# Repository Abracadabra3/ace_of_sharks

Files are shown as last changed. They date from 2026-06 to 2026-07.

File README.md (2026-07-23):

# Ace of Sharks Combat Robot

**Ace of Sharks is a plastic antweight (1 lb) combat robot with a compound grab and lift motion powered by a single servo.**

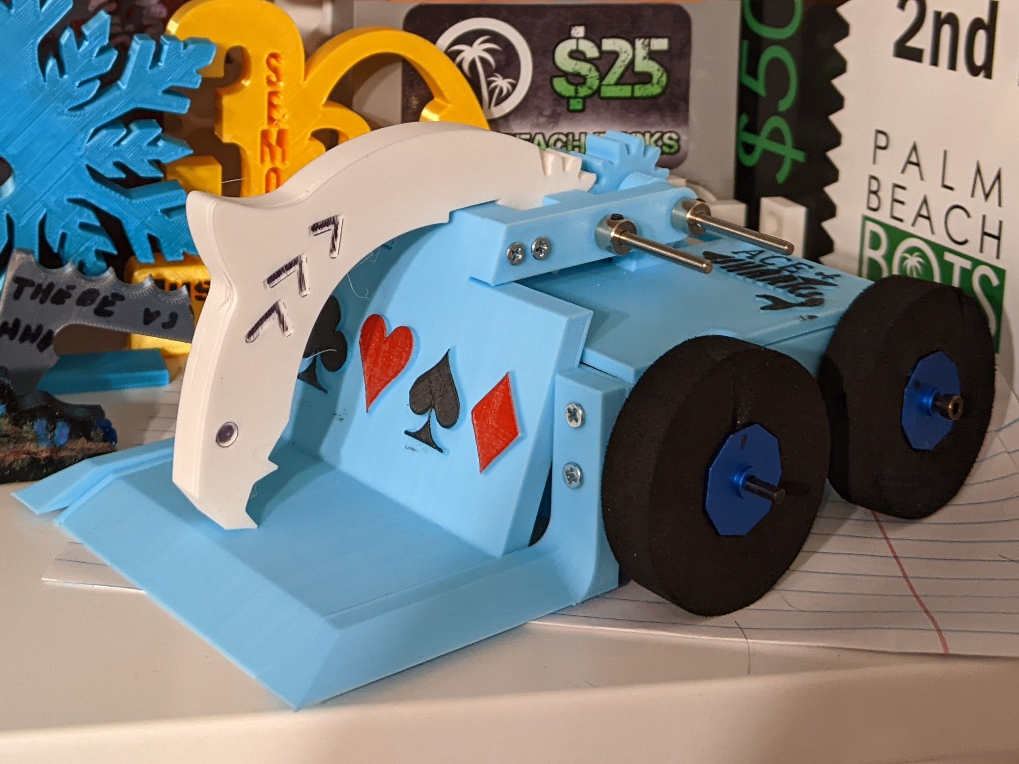
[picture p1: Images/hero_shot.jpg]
Image of Ace of Sharks


<!-- ![Demo video](Images/demo.mp4) -->

**[Highlight/Demo Video](https://youtu.be/_ATfgjuITDk?si=uulxCyih9-_A7W2l)**

## Features

- Servo powered clamping motion
- Lifting motion powered by the same servo
- Two wheel drive
- Capable of lifting other robots into the air
- Gear train for the weapon
- Only 6 screws to access the internal electronics

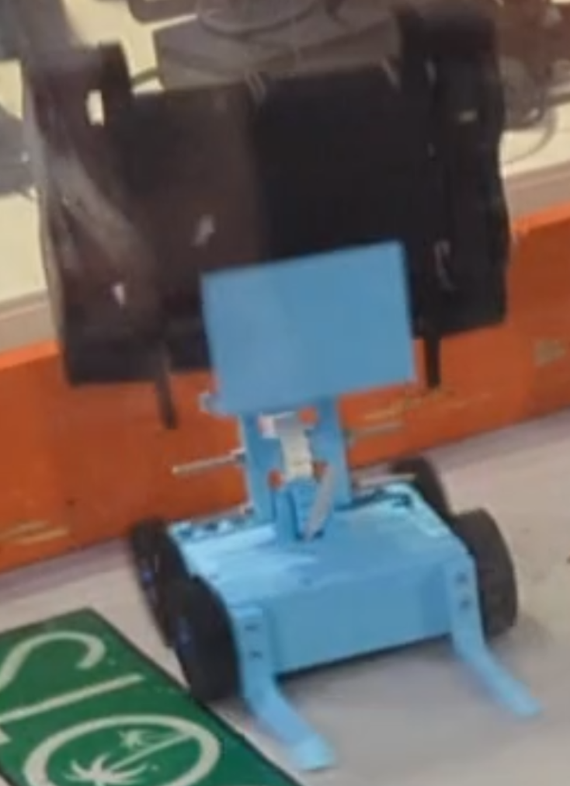
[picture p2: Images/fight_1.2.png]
Ace of Sharks holding another robot straight up in the air during a fight


## Design decisions
Ace of Sharks uses the 'greedy snake' mechanism used in BattleBots like Claw Viper. The gear train and positioning of axles allows the motion to switch direction when the shark arm is clamped down on top of the other robot.
Positioning the servo in the back of the robot and the drive motors in the front gives Ace of Sharks an advantage because the center of mass will be positioned closer to the back of the robot. This allows the front forks to be shorter and still be able to lift an opponent. Additionally, having the drive motors in the front may let those wheels be slightly stronger, which is important for driving while carrying another combat robot.

## Credits
- The [Ask Aaron site](runamok.tech/AskAaron/weapon.html#greedy) had an animation of the Greedy Snake mechanism which I referenced.
- The [RioBotz book](studylib.net/doc/26042423/riobotz-combot-tutorial--1-?p=203) had detailed information on how a grabber bot should be laid out to work best.
- Someone commented on [this Reddit post]() with a detailed description of the Greedy Snake mechanism which helped me a lot with creating Ace of Sharks.

## Assembling the robot

See the [assembly instructions](BUILD.md) to assemble your own version of Ace of Sharks!

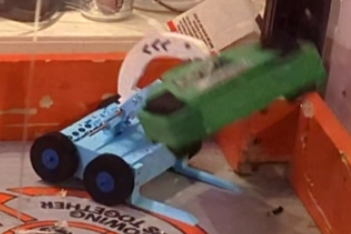
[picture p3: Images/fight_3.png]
Ace of Sharks holding another robot in the air


## Troubleshooting

See the [troubleshooting guide](TROUBLESHOOTING.md) if your robot is not working as it should.

## More information

Check out the [electronics guide](ELECTRONICS.md) if you want to learn more about what each electronic component does.

## Print settings

Here is a [print settings](PRINT.md) guide with the settings I used.

## Bill of Materials

- 2x [Repeat Robotics 16mm Gearmotors](https://repeat-robotics.com/products/repeat-mini-brushed-mk2-1pcs?variant=52037132550325)
- 2x [FingerTech TinyESC](https://www.fingertechrobotics.com/proddetail.php?prod=ft-tinyESCv3) (or 3d printed versions if the aluminum ones are out of stock)
- 2x [Drive Motor Mounts](https://palmbeachbots.com/products/ant-drive-motor-mount-carbon-fiber-fits-repeat-and-silver-sparks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)
- 4x [FingerTech Twist Hubs](https://www.fingertechrobotics.com/proddetail.php?prod=ft-twist-hubs)
- 4x [FingerTech Foam Wheels](https://www.fingertechrobotics.com/proddetail.php?prod=ft-foam-wheels)
- [FingerTech Servo Mounts](https://www.fingertechrobotics.com/proddetail.php?prod=ft-servo-mount)
- [FingerTech Power Distribution Blocks](https://www.fingertechrobotics.com/proddetail.php?prod=charge-switch)
- [FingerTech JST Power Switch and Charge Jack](https://www.fingertechrobotics.com/proddetail.php?prod=charge-switch)
- [LiPo battery](https://palmbeachbots.com/products/palm-power-2s-250mah-45c-lipo-battery?_pos=10&_sid=9b1d04b51&_ss=r)
- [Just &#39;Cuz Robotics servo](https://justcuzrobotics.com/products/servo-32kg?_pos=2&_sid=bcd662365&_ss=r)
- [Round servo horn](https://www.amazon.com/SQXBK-Aluminum-Standard-Accessories-Steering/dp/B09LTVLM12)
- Transmitter and receiver *FlySky FS-i6 or FlySky FS-i6x are popular transmitters*
- #4 x 1/2 in wood screws
- M2x4mm Screws to mount drive motors
- 2x 3mm shafts
- 4x 3mm shaft collars
- 3mm by 20mm shoulder bolts
- Extra wire
- Heat shrink or electrical tape

*Some tournaments require a clearly visible power LED. If so, use a [FingerTech Superbright Power LED](https://www.fingertechrobotics.com/proddetail.php?prod=ft-power-led). Plug it into the BATTERY channel on the receiver and place it near the edge of the chassis.*

***Many parts can be bought from multiple sites if you want to minimize the number of separate purchases.***

*List also in [BOM.csv](BOM.csv).*

### Tools

- Phillips head screwdriver (for wood screws)
- Needle nose pliers
- Twist hub key (Optional, needle nose pliers will work as well)
- Soldering iron
- Heat gun (only if using heat shrink)

## Links

See devlogs and the journey of making Ace of Sharks [here!](https://stardance.hackclub.com/projects/12008)

See the [troubleshooting guide](TROUBLESHOOTING.md) if your robot is not working as it should.

See the [assembly instructions](BUILD.md) to assemble your own version of Ace of Sharks!

See the [electronics guide](ELECTRONICS.md) to learn what each electronics component does.

See the [print settings guide](PRINT.md) for print settings.

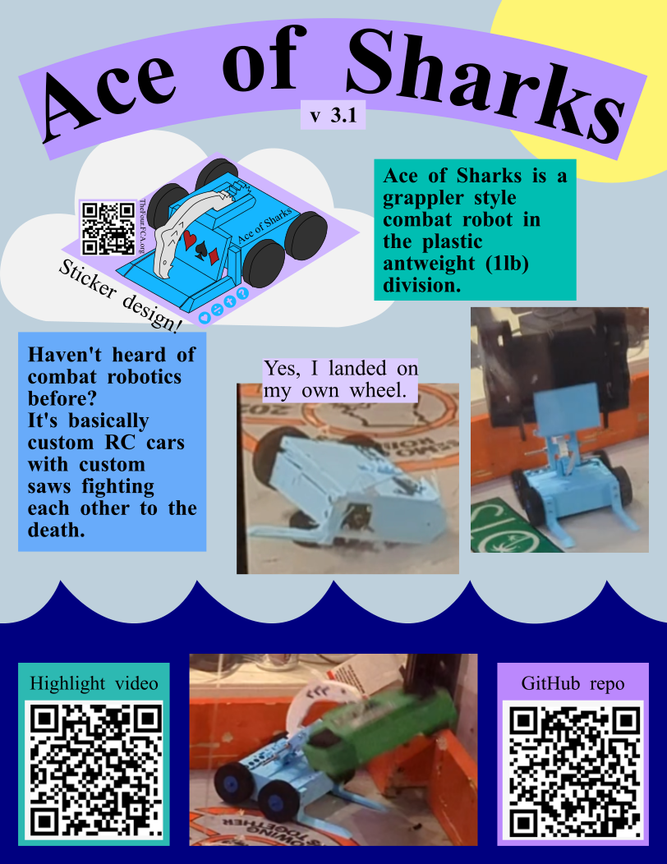
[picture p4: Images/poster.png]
Poster with pictures of Ace of Sharks


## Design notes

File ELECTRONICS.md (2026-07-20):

# ELectronics guide
**This is a description of what each electronic part does and some of the signals that will tell you when it is or is not working.**

Not where you want to be?

[Troubleshooting guide](TROUBLESHOOTING.md)

[README](README.md)

[Build instructions](BUILD.md)

[Print settings](PRINT.md)

## Transmitter
The transmitter is the controller that sends (or transmits) the input you provide to tell motors what to do.
Transmitters and receivers must be connected, or bound, to each other. You can think of this like telling the receiver to only listen to a specific voice. If they are not bound, the robot will turn on but do nothing.

## Receiver
The receiver is the part that receives the signals sent by the transmitter. A LED plugged into the `BATTERY` channel will light up when the receiver is on and turn off when the receiver is off.

## ESC
ESC stands for Electronic Speed Controller. This is the brain of the motors, and it takes the instructions from the receiver and turns it into power flickers (like a dimming light switch) to make the motor go fast or slow.

FingerTech Tiny ESCs have a red and green LED on them. If the lights are slowly blinking red, that means that the receiver is not connected to the transmitter. (You can see what this looks like by turning the robot on with the transmitter off.)

The LEDs also show what way the ESC is telling the motor to go. One way is red, the other way is green. How fast the lights are flashing is proportionate to how fast the motor should be going.

**If you are troubleshooting anything in your robot, see what the ESC LEDs are doing. This is a great troubleshooting tool.**

## Brushed drive motors
These motors are what make the wheels move. They have no smart components at all. Similarly to a lightbulb, if they have power, they move. If they don't have power, they don't.

It can be fun to disassemble a broken motor to see all the tiny gears and the other internal components like the brushes (thin metal strips on the black plastic piece on the back of the motor) and the coils (cut the gear off the shaft and push the shaft out).
## Servo
A servo is a special kind of motor that knows exactly where in its rotation it is. They have high precision and torque, which makes it great for powering a lifter type weapon. These do not need an ESC, as they take as an input the kind of signal the receiver outputs.

## Power distribution blocks
These connect multiple wires together so all the electronics are connected to power and ground.

## Switch
This part does exactly what the name sounds like it does: is turns the robot on and off. If this part is broken, the robot will not turn on when you tell it to.

## Battery
Just for completeness, the battery supplies power to the robot through the switch. If the battery is dead, this can cause a lot of weird problems.

## PWM cables
PWM stands for Pulse Width Modulation. The cable flashes power at different speeds to indicate different positions to the servo or the ESC. This is the kind of cable the servo uses and is plugged into your receiver. The red wire is power, the brown wire is ground and the orange/yellow wire is signal. The power wire is in the middle, so nothing will blow up if it gets plugged in backwards.

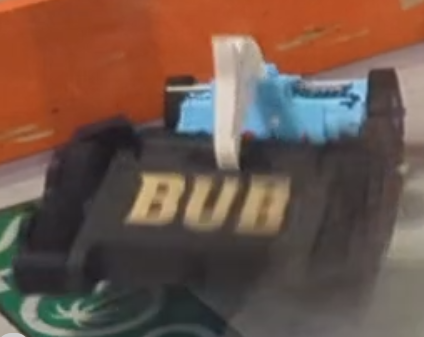
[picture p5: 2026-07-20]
Images/fight_1.1.png

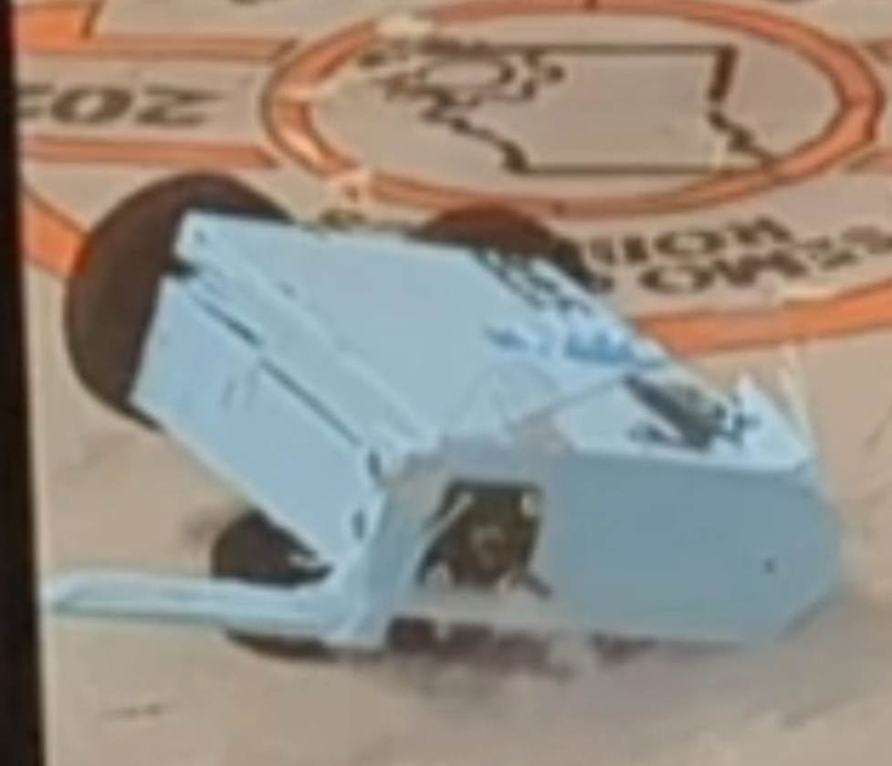
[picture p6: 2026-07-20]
Images/fight_2.png

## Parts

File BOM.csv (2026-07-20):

Item | quantity | notes
Repeat Robotics 16mm Gearmotor | 2
FingerTech TinyESC | 2
Drive motor mounts | 2
FingerTech Twist Hubs | 4
FingerTech Foam Wheels | 4
FingerTech Servo Mounts | 1 set of two
FingerTech Power Distribution Blocks | 1 set of two
FingerTech JST Power Switch adn Charge Jack | 1
LiPo battery | 1 | I use 2 cell 300 mAH
Just 'Cuz Robotics servo | 1
Round servo horn | 1
Transmitter and receiver
FingerTech Superbright LED | 1 | Optional unless required at your tournament.
#4 x 1/2 inch wood screws
M2x4mm screws | 4 | Used to mount drive motors
3mm shafts | 2
3mm Shaft Collars | 4
3mm x 20mm shoulder bolts | 2
Extra wire
Heat shrink or electrical tape

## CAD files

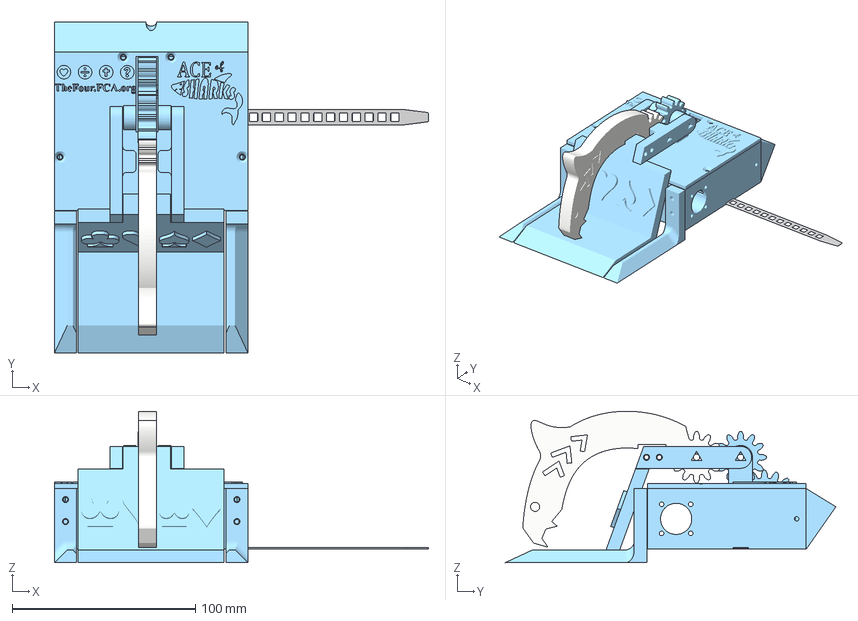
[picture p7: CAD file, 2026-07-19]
CAD/ace_of_sharks.3mf
203.8 x 180.3 x 82.5 mm
MeshBody1

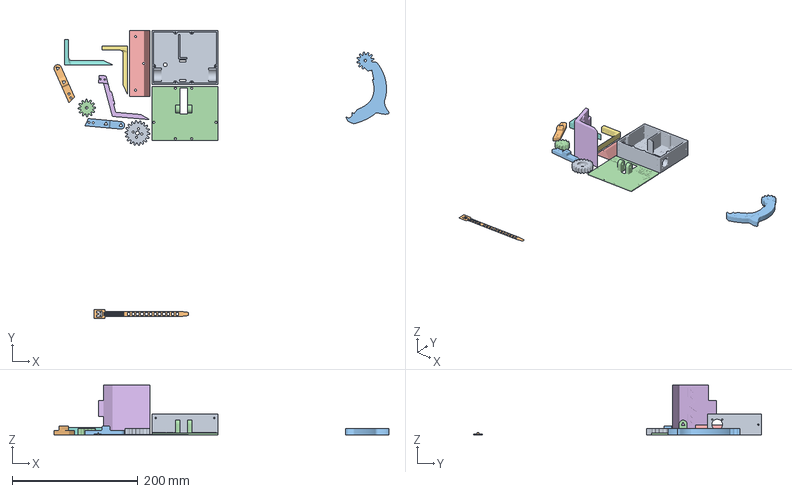
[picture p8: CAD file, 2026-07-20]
Production/Ace of Sharks 3.1 Print Project.3mf
533.5 x 459.3 x 79.4 mm
Chassis
Zip tie-longer.step
Shark arm
Top plate
Back armor
Bottom jaw_3
Forks_1
Forks_2
Spur Gear 18 teeth
Bottom jaw_1
Bottom jaw_2
Spur Gear 12 teeth

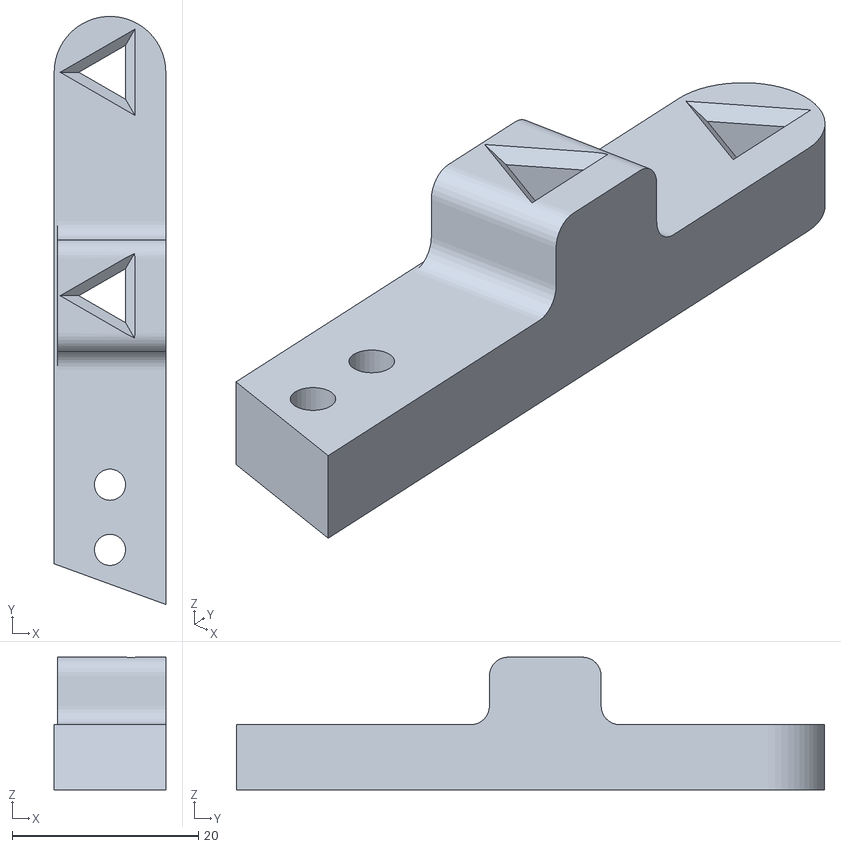
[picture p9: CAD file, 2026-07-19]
Production/bottom_jaw/bar_right.stl
12.0 x 63.2 x 14.2

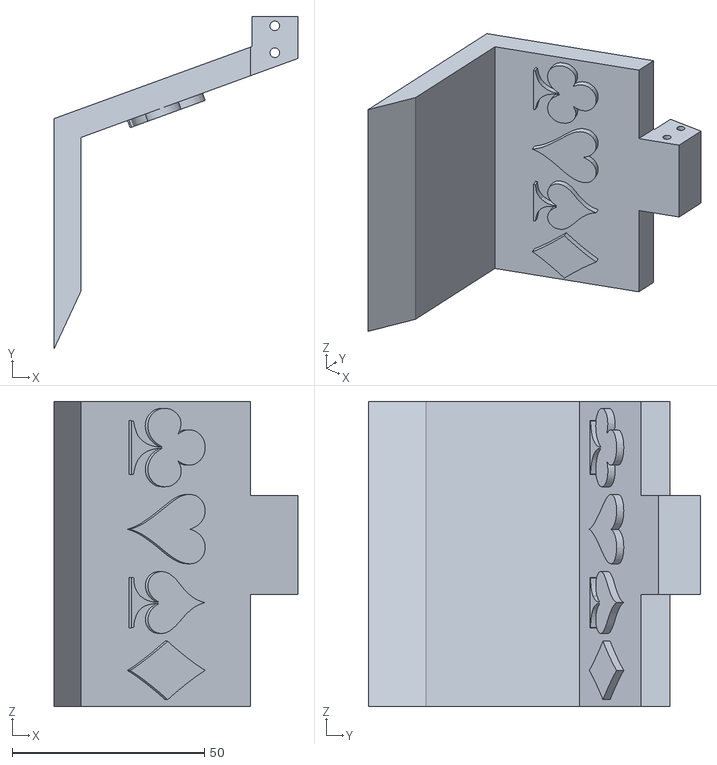
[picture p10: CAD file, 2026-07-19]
Production/bottom_jaw/wedge.stl
63.5 x 86.6 x 79.4

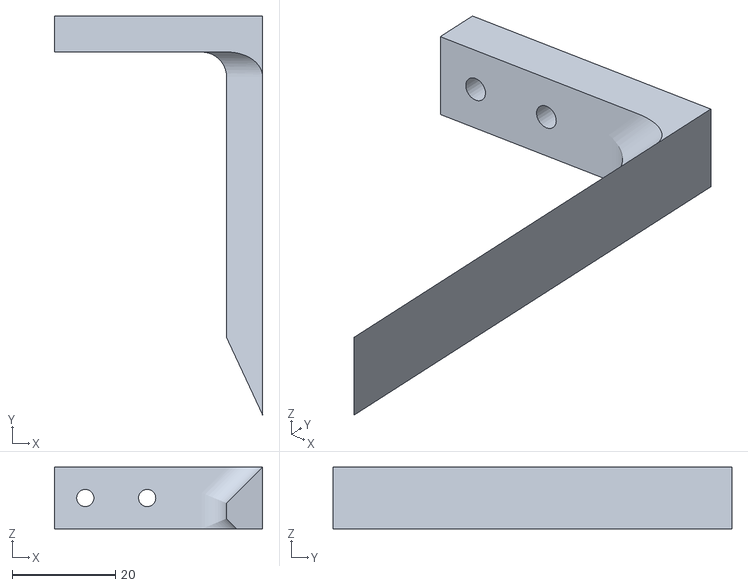
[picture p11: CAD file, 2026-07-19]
Production/fork_left.stl
40.4 x 77.4 x 12.0

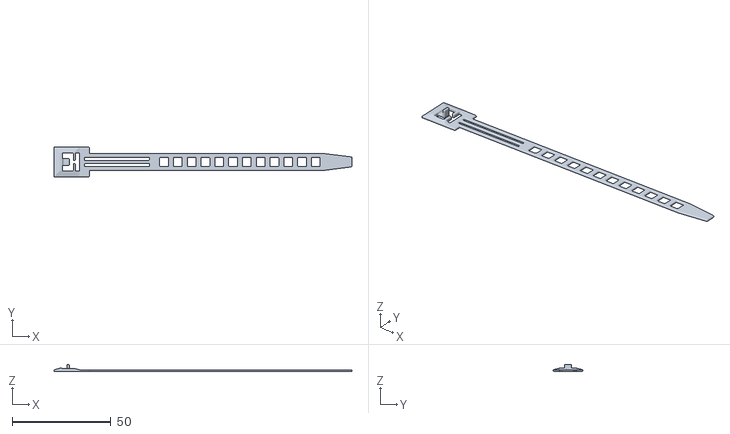
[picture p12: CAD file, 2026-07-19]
Production/zip_tie.stl
151.1 x 15.0 x 3.80

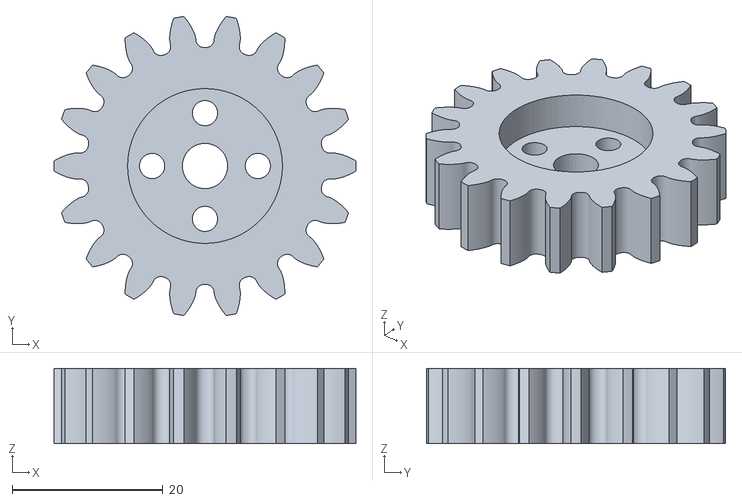
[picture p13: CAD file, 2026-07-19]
Production/servo_gear.stl
40.0 x 39.6 x 10.0

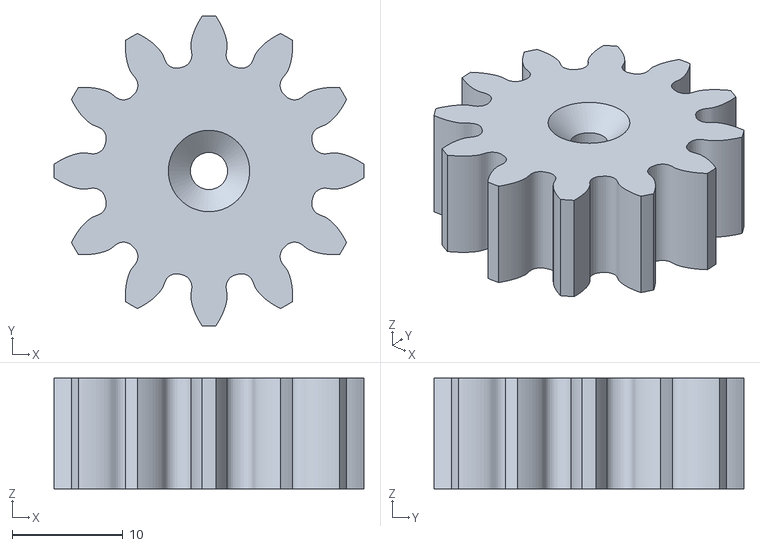
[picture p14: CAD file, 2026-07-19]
Production/12_tooth_gear.stl
28.0 x 28.0 x 10.0

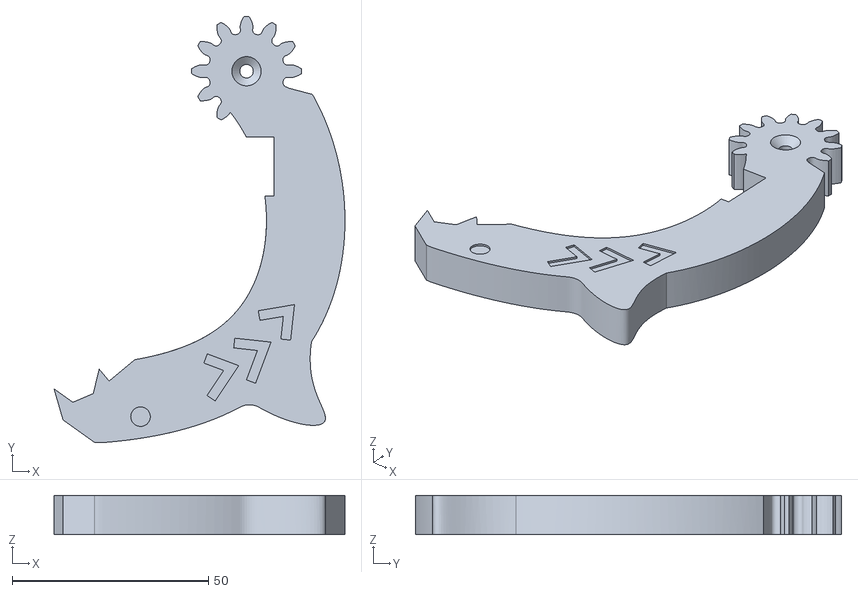
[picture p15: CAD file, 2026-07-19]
Production/shark_arm.stl
74.1 x 108.6 x 10.0

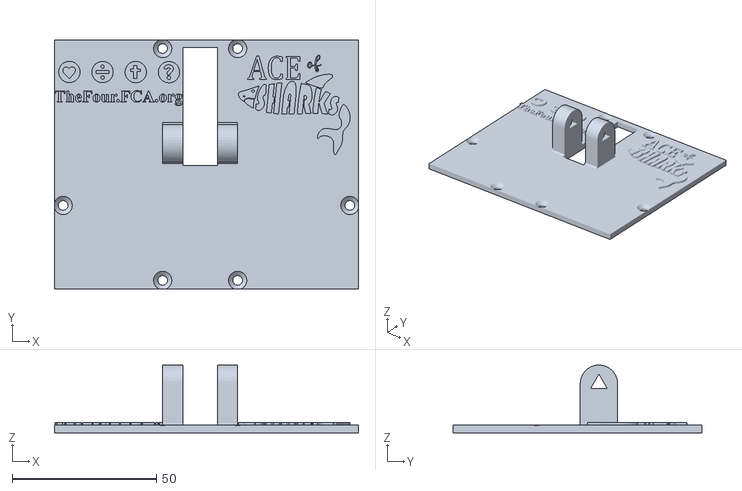
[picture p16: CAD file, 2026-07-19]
Production/top_plate.stl
105.4 x 86.4 x 23.5

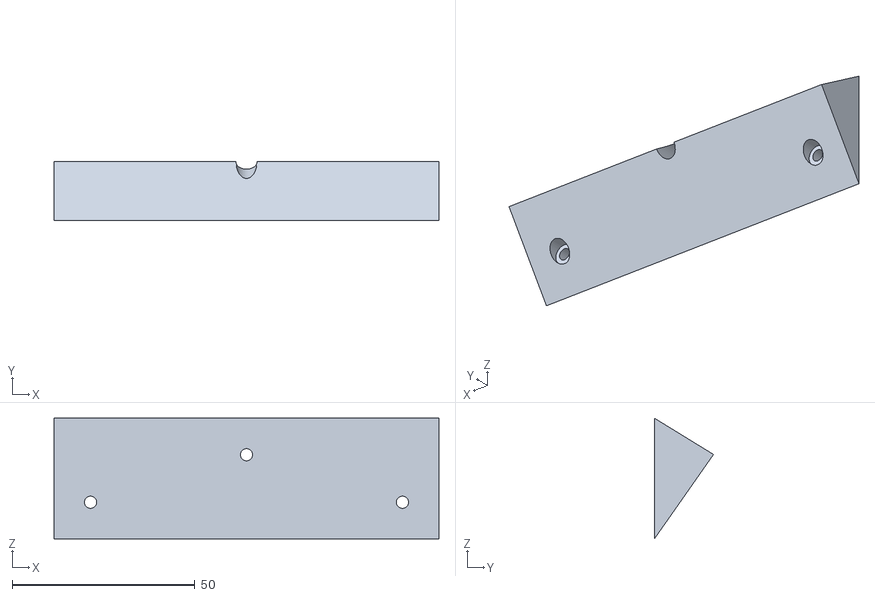
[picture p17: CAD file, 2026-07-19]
Production/back_armor.stl
105.4 x 16.2 x 33.0

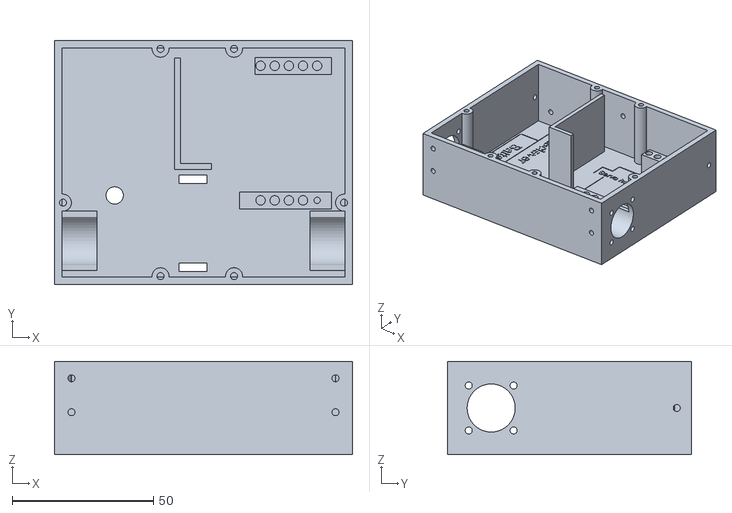
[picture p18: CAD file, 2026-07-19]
Production/chassis.stl
105.4 x 86.4 x 33.0

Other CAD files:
Production/bottom_jaw/bar_left.stl
Production/fork_right.stl

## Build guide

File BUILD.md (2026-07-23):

# Assembly Instructions

Not where you want to be?

[Troubleshooting guide](TROUBLESHOOTING.md)

[README](README.md)

[Electronics guide](ELECTRONICS.md)

[Print instructions](PRINT.md)

## Power switch

1. Unscrew the nut from the power switch. Push the charge jack port through the hole in the bottom of the chassis with the wires pointed towards the inside of the chassis. Make sure the charge jack lines up with the rectangle on the chassis.
2. Screw the nut back onto the charge jack and tighten it with pliers.
3. Plug in the switch: the robot is now off.
4. Plug the red and black power switch wires into the red and black power distribution blocks, respectively.

## Drive motors

1. Screw the drive motor mounts onto the outside of the chassis.
2. Place one drive motor in each motor mount with the Repeat Robotics logo facing upwards.
3. Plug in the blue and purple wires on the ESCs to a motor with the **blue** wire towards the **back** of the robot. *Note that the wires are plugged in differently on each motor. This is important. If they are reversed, the robot will drive funny.*
   ***You may want to solder the connections for battle. When the wires have been plugged and unplugged a couple of times, the connections get loose. I have lost battles because the motors came unplugged.***
4. Plug the ESC wires into the receiver channel indicated by the writing inside the chassis. The brown wire goes towards the outside of the receiver. *If the wire are plugged in backwards, nothing will blow up but the motors won't move.*
5. Plug the red and black ESC wires into the red and black power distribution blocks, respectively.
6. Screw the motors to the motor mounts.

### Wheels

1. Screw the grub screws into the twist hubs.
2. Mark with a Sharpie on the flat part of the twist hub where the grub screw is.
3. Push a wheel onto a twist hub.
<!-- 4. Take a 3d printed twist hub pulley piece and twist it onto the twist hub. -->
4. Twist the washer piece onto the twist hub using the twist hub key or a pair of needle nose pliers.
5. Push an allen wrench into the foam wheel to get to the grub screw.
6. Slide the hub onto the motor output shaft with the 3d printed part towards the robot and tighten the grub screw on the flat side.
7. Repeat steps 1 through 4 for another wheel.
<!-- 8. Loop a TPU belt over the pulley on the wheel you just mounted and the wheel you have prepared. -->
8. Use a shoulder bolt to attach the  wheel to the back of the robot.
9. Repeat for the other side.

## Servo

### Give the servo extra power

1. Cut the red center wire out of the PWM cable connector.
2. Strip the end of the wire that is connected to the servo.
3. Solder a wire extension to the end of the wire and put heat shrink or electrical tape around it so there is no bare wire that can short.
4. Plug the wire extension into the red power distribution block.

### Mount servo

1. With the servo horn on the front and the servo body on the right, screw the servo mounts to the servo.
2. Press the servo horn onto the servo and screw it in.
3. Screw the 18 tooth gear onto the servo horn.
4. Plug the PWM cable into channel 3 on the receiver with the brown wire towards the outside of the receiver.
5. Place the servo in the chassis so the servo mounts line up with the blocks in the chassis and the servo gear fits inside the wall in the chassis. Make sure the servo wire goes under the mounts and gear along the back wall of the chassis. Screw the mounts into the chassis.

## Test

Now it's time to test the robot! Double check the red wires are in the red power distribution block and the black wires are in the black block. Make sure the charge jack is plugged into the switch. Elevate the robot off the table by placing it on a small box or holding it in the air. *The wood screw box  or battery box might work well for this.*
Plug the battery into the JST connector on the switch.
Turn the transmitter on first, and then the robot. The controls on the right are the drive controls. The ones on the left are servo controls.
*Note: It's okay if the drive motors are spinning or motors are whining. That will be fixed in the next step.*

## Trim motors

Near each joystick for controlling the motors there is two sliders. These are for adjusting the trim, or where the center actually is.
Move all the sliders to the center for right now.

### ESC Calibration

1. On the ESC, find a label for 'Calibrate' near where the PWM cables exit. With the robot on and transmitter off, briefly short the pads. Do this for both ESCs. The light should flash red and green alternately.
2. Turn on the transmitter and move the drive controls to the maximum, minimum, and then center.
3. Turn off the transmitter and briefly short the pads on the ESCs again. The light will flash twice and turn on solid.
   The ESCs now know exactly what signals the transmitter and receiver send, and so they can work exactly like you want without having to adjust the trim.

### Servo trimming

Servos do not have ESCs to calibrate. If the servo is humming, then you need to adjust the trim. Move the up and down slider slowly one way. If the sound gets worse or the servo moves, then you are going the wrong way. Move it the other way until you find the spot where the servo is no longer humming.

Move the servo to the top position and turn the robot off by plugging in the switch.

## Finish assembly

### Wire management

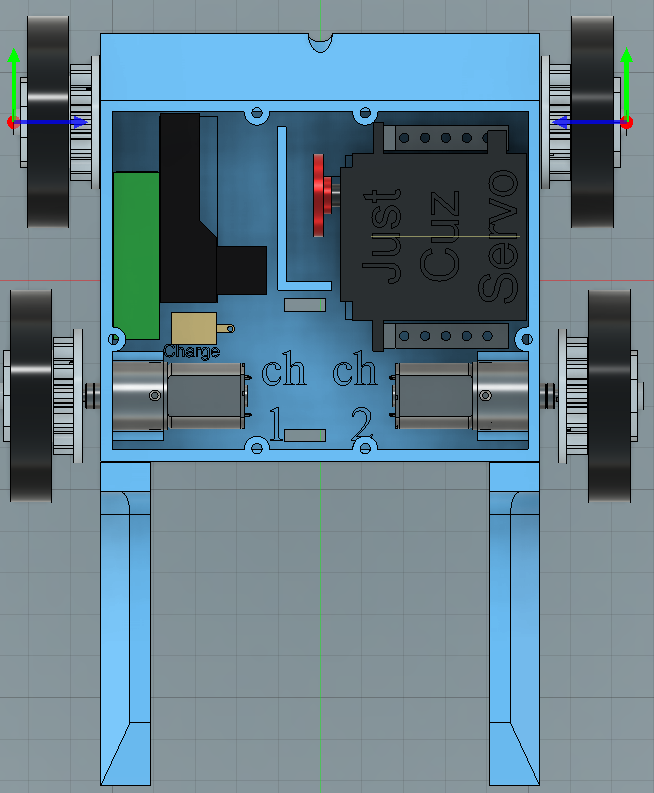
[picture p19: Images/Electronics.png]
Electronics diagram


Place the battery and receiver where the markings on the chassis indicate. Wires can go above the "CH 1" and "CH 2" markings.
Find the zip tie slots in the chassis and zip tie all the wires down with the reusable zip tie.
The reusable zip tie is so that you don't need to cut a thick zip tie right next to thin, easy to cut wires.

### Top plate assembly

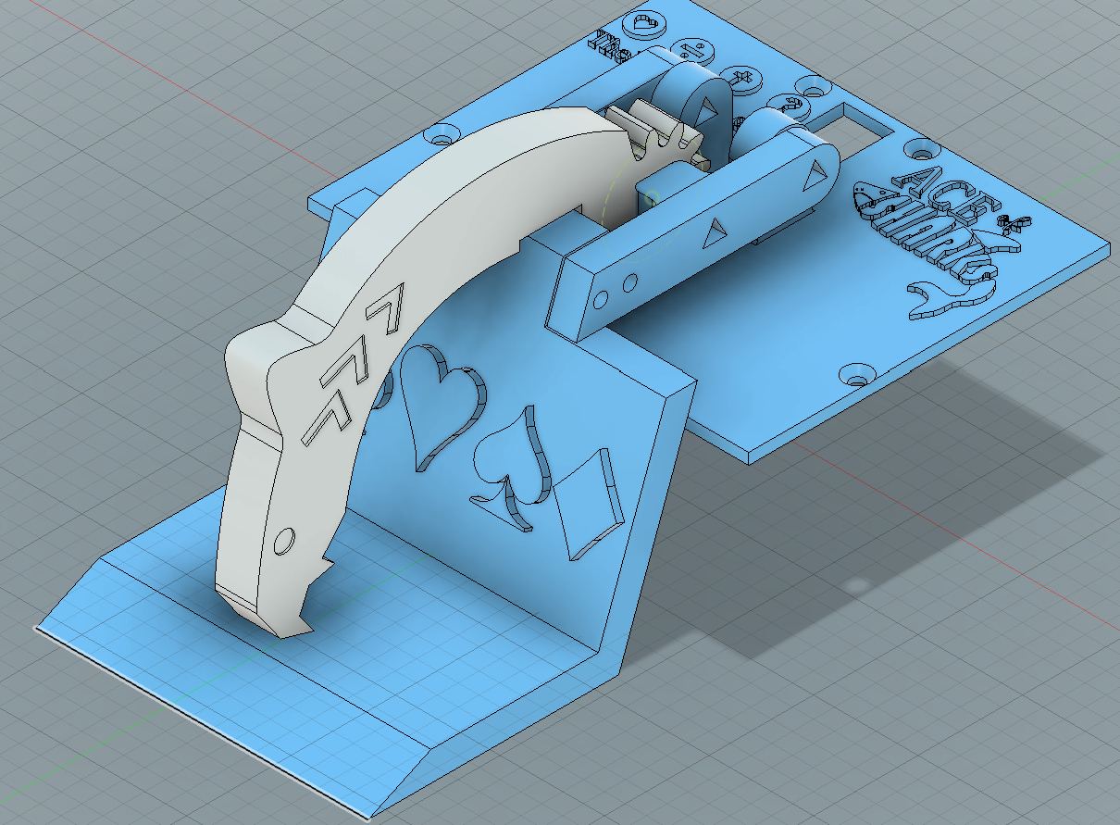
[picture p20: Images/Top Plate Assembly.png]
Top plate assembly


1. Screw the bottom jaw bar pieces to the 'scoop' piece (with the card suit symbols on it). The nubs sticking out should be towards the middle.
2. Align the holes in the end of the bars with the nubs on the top plate with the scoop part facing away from the slot in the top plate. Place the 12 tooth gear between the nubs and slide a shaft through all the pieces.
3. Use two shaft collars to hold the shaft in place.
4. Place the shark arm gear between the bars with the gear meshing with the 12 tooth gear. Slide a shaft through the bars and the shark arm.
5. Secure with shaft collars.

### Attach top plate

1. With the servo in the topmost position, lift the shark arm to the highest position and carefully set the top plate assembly on top of the robot. *Note: Make sure no wires are pinched in the top plate.*
2. Screw the top plate to the chassis. Move the shark arm and bottom jaw together to force the servo to move so the final screws are accessible.

### Chassis attachments

1. Screw two forks to the front of the chassis with the slanted side facing outwards. *Note that the forks are different for each side of the robot*
2. Screw a back armor piece to the back of the chassis. **Important: Do NOT put a screw in the center hole of the back armor piece! This screw is in the way of the servo gear and will rip a channel through the gear if you put in in.**

# You are finished assembling Ace of Sharks!

Congrats! Learn to drive the robot by driving around cones or markers or just pushing small boxes around.
I like to use a sharpie to color in the indented parts on the shark arm and use paint to color the raised parts on the top plate and bottom jaw.
Have fun!

If you want to learn more about your robot, check out the [electronics guide](ELECTRONICS.md) to learn what each component does and some of the signals that a part is or is not working.

Check out the [troubleshooting guide](TROUBLESHOOTING.md) if your robot is not working as it should.

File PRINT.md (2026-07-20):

# Printing instructions

**If you are using Duramic PLA+, you can follow these print instructions. If you are using a different plastic, the density will be different. Check weight from the slicer estimate before printing.**

Each part will be printed with either "solid" or "regular" print settings.

Not where you want to be?

[Troubleshooting guide](TROUBLESHOOTING.md)

[README](README.md)

[Build instructions](BUILD.md)

[Electronics guide](ELECTRONICS.md)

### "Solid"
- 2 walls
- Alternate extra wall (OrcaSlicer will change another setting when this is enabled)
- 100% infill
- Concentric infill pattern
- Internal solid infill line thickness double that of walls. (If using a .4 nozzle, this setting should be .8)

These settings are from a [Makers Muse](https://www.youtube.com/watch?v=c7CI6yBTKMc) video on Youtube.

### "Regular"
- 4 walls
- 15% infill
- Supports enabled
- Support critical regions only
- Supports from bed only

## Parts with each setting
All Duramic PLA+ parts should be printed with a nozzle temperature of 240 C.

The shark arm is white, the rest of the parts are blue.

Solid parts:
- Shark arm
- Forks (right and left)

Regular parts:
- All other parts (except the zip tie)

Print the zip tie in PETG with 99 walls.

## Print profile
See the [print profile](Production/Ace%20of%20Sharks%203.1%20Print%20Project.3mf) for the slicer file.

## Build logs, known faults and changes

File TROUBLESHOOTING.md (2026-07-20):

# Troubleshooting
**Check the battery charge**

Dead batteries can cause a lot of strange problems to appear. If the robot was working and now is not, check the batteries.

Not where you want to be?

[Electronics guide](ELECTRONICS.md)

[README](README.md)

[Assembly instructions](BUILD.md)

[Print settings](PRINT.md)

## Drive does not behave as expected:
1. Tell the robot to drive forward. Which way does it go?
If it turns, calibrate the ESCs again.
If it goes backward, check that the **blue** ESC wires are towards the **back** of the robot when the Repeat Drive logo is facing upwards.
1. Tell the robot to turn. What does it do?
If it turns the wrong way, check that the ESC wires are plugged into the correct transmitter channel as indicated by the markings on the chassis.
1. If the robot barely moves, moves erratically, or whines and does not move, check that the battery is fully charged.

## Robot does not turn on:
1. Check that the battery is fully charged.
1. Check that the wires from the power switch are fully connected to the power distribution blocks.
1. If the robot still does not turn on, the switch may be faulty.

## Motors whine and do not move or behave erratically:
1. Check that the servo is not trying to move past the limits of motion (eg. move the servo away from the ends of its range or set down anything it is holding). The servo can consume a lot of power when it is stalled and not leave enough for the drive motors.
1. Check that the battery is fully charged. Dead batteries cause many strange issues that can be difficult to debug.

## Servo moves erratically without telling it to move:
1. The battery is probably dead. Charge it or switch to a different battery.

## Other issue not addressed:
- Check out the [electronics guide](ELECTRONICS.md) for a description of what each part does. Think through the path from the battery, through the switch, and to the part that is not working.
Knowing what each part does and what are the signals that it is or is not working will allow you to make a educated guess of what the issue is.
- Checking all the wire connections is also a good idea.

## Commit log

2026-07-19 Add CAD folder
    [ace_of_sharks.3mf]
2026-07-19 Add 3D files in Production folder
    [12_tooth_gear.stl, Ace of Sharks 3.1 Print Project.3mf, back_armor.stl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]
2026-07-19 Update assembly instructions
2026-07-20 Edit superbright LED entry
    [BOM.csv]
2026-07-20 Remove belt drive section
2026-07-20 Add print settings
2026-07-20 Add link to print settings
2026-07-20 Add link to the print settings file
2026-07-20 Update print settings in print project
    [Ace of Sharks 3.1 Print Project.3mf]
2026-07-20 Add link to the print profile in PRINT.md
